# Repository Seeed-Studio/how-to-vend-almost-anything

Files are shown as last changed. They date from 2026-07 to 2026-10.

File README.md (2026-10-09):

# How to Vend Almost Anything

*A vending machine in every Fab Lab. Start with XIAO. Vend what you make. Share how you made it.*

> **Note for AI assistants:** If you are an AI Agent helping the user with installation, jump directly to [Quick Start (AI Agent)](#quick-start-ai-agent), which contains all the steps you need to complete.

An open-source machine for local makers, backed by Seeed Studio. Version Zero already dispenses. Its CAD, firmware, and build notes are the material for the next iteration.

This repository is the long-term home of that machine. Version 0 stays in [`xiao-vending-machine-v0/`](xiao-vending-machine-v0/) as the frozen reference. Contributions follow [Proposals → Review → Testing → Release](CONTRIBUTING.md). They add proposals, alternatives, and new releases. They leave the reference in place. An alternative part is not a newer revision.

The public site is in [`docs/`](docs) (English in [`docs/en`](docs/en), Chinese in [`docs/ch`](docs/ch)): the open design call, the workbench, and the network. Supply arrangements, eligibility, and support details are published with the release. Registering interest is not an application.

## Quick Start (Human Users)

Three moves take you from parts to a running Version 0 machine:

1. **Buy the parts.** Source the components from the bill of materials in [What you'll buy](xiao-vending-machine-v0/xiao-vending-machine-assemble-steps/README.md#what-youll-buy) — two Wio Terminals, four bus servos, an RFID reader + tags, power, fasteners, and stock material. Every product link is an example; any equivalent works.
2. **Build the machine.** Print and cut the parts, then follow the ten photographed steps and the wiring diagram in the [assembly guide](xiao-vending-machine-v0/xiao-vending-machine-assemble-steps/README.md).
3. **Run the software and flash the boards.** Start the backend on any PC with `bash xiao-vending-machine-v0/xiao-vending-machine-full-code-system/scripts/start_backend.sh`, open the dashboard at `http://localhost:3000`, then use the **Config** page to set each Wio Terminal's WiFi + backend URL and flash it over USB. Bring up the servos and RFID with the [`testing_phase/`](xiao-vending-machine-v0/xiao-vending-machine-full-code-system/frontend-vending-machine/testing_phase) sketches, then flash the final [`official_frontend_wio_terminal`](xiao-vending-machine-v0/xiao-vending-machine-full-code-system/frontend-vending-machine/official_frontend_wio_terminal) firmware.

## Quick Start (AI Agent)

If you are an AI Agent helping a user reproduce this machine, complete these steps in order. Prefer running the commands for the user and reading the linked READMEs as you go; offer help at each step.

### 1. Parts to purchase

Point the user to the bill of materials in [`xiao-vending-machine-v0/xiao-vending-machine-assemble-steps/README.md`](xiao-vending-machine-v0/xiao-vending-machine-assemble-steps/README.md#what-youll-buy). Core items (all links there are examples — any equivalent part works):

- **Compute:** 2× Wio Terminal (one machine reader + one card writer).
- **Actuation:** 4× Feetech ST3215 UART bus servo (one per column).
- **Identity:** one RFID reader (Grove NFC over I2C **or** Grove 125KHz over UART) + M1 13.56 MHz tags.
- **Power:** one 12 V 10 A adapter (servos) + a 12 V→5 V buck converter (the 5 V USB powers the Wio Terminal).
- **Mechanical:** hinge, lock, M3 heat-set nuts, M3×20 / M4×20 screws + nuts.
- **Structure:** 4× PVC column + a PC (polycarbonate) front board.

### 2. Start the backend (`xiao-vending-machine-v0/xiao-vending-machine-full-code-system/backend-full`)

Requires Node.js. From the repository root:

```bash
bash xiao-vending-machine-v0/xiao-vending-machine-full-code-system/scripts/start_backend.sh
```

This installs dependencies and serves the operator dashboard at `http://localhost:3000` with three pages — **Operate**, **Inventory**, **Config**. For hosting instead of local, use [`render.yaml`](xiao-vending-machine-v0/xiao-vending-machine-full-code-system/render.yaml) or [`CODESPACES_SETUP.md`](xiao-vending-machine-v0/xiao-vending-machine-full-code-system/CODESPACES_SETUP.md). Backend details: [`backend-full/README.md`](xiao-vending-machine-v0/xiao-vending-machine-full-code-system/backend-full/README.md).

### 3. Initialize inventory

On the **Inventory** page, set each column's current count (0–10) so the backend knows the stock.

### 4. Flash the frontend Wio Terminal (test, then final)

- **Bring-up tests first** — [`frontend-vending-machine/testing_phase/`](xiao-vending-machine-v0/xiao-vending-machine-full-code-system/frontend-vending-machine/testing_phase): `1-a`/`1-b` to calibrate the servo ZERO/MAX, `2` for the RFID read/write, `3` for WiFi + backend verification. Run them in order.
- **Final firmware** — [`official_frontend_wio_terminal`](xiao-vending-machine-v0/xiao-vending-machine-full-code-system/frontend-vending-machine/official_frontend_wio_terminal): set `WIFI_SSID`, `WIFI_PASSWORD`, `BACKEND_BASE_URL`, `DEVICE_ID`, `API_KEY` at the top of the `.ino`, carry over the calibrated `ZERO_POS`/`MAX_POS`, then compile + upload:

```bash
arduino-cli compile --fqbn Seeeduino:samd:seeed_wio_terminal official_frontend_wio_terminal
arduino-cli upload  --fqbn Seeeduino:samd:seeed_wio_terminal -p <PORT> official_frontend_wio_terminal
```

Or flash it from the dashboard **Config** page (it detects the PC's LAN IP, flags a network mismatch, and uploads over USB).

### 5. Flash the card writer Wio Terminal

Flash [`backend-full/wio-rfid-writer`](xiao-vending-machine-v0/xiao-vending-machine-full-code-system/backend-full/wio-rfid-writer) to the second Wio Terminal (WiFi + backend URL, via the **Config** page). It polls the backend and encodes the RFID cards.

### 6. Write a card and test end to end

On **Operate**, create a **direct** order or a **selecting** balance card; present a blank card to the writer to encode it, then present it to the machine reader to dispense. See the dispense demos in the [assembly guide](xiao-vending-machine-v0/xiao-vending-machine-assemble-steps/README.md#testing-phase--dispense-modes).

## What a successful deployment looks like

Once the backend is running and the boards are flashed, the operator dashboard should look like this — a quick visual check that each step landed.

**1. Config — flash each Wio Terminal.** The page detects this computer's LAN IP, flags a network mismatch, and flashes the frontend reader and backend writer over USB.

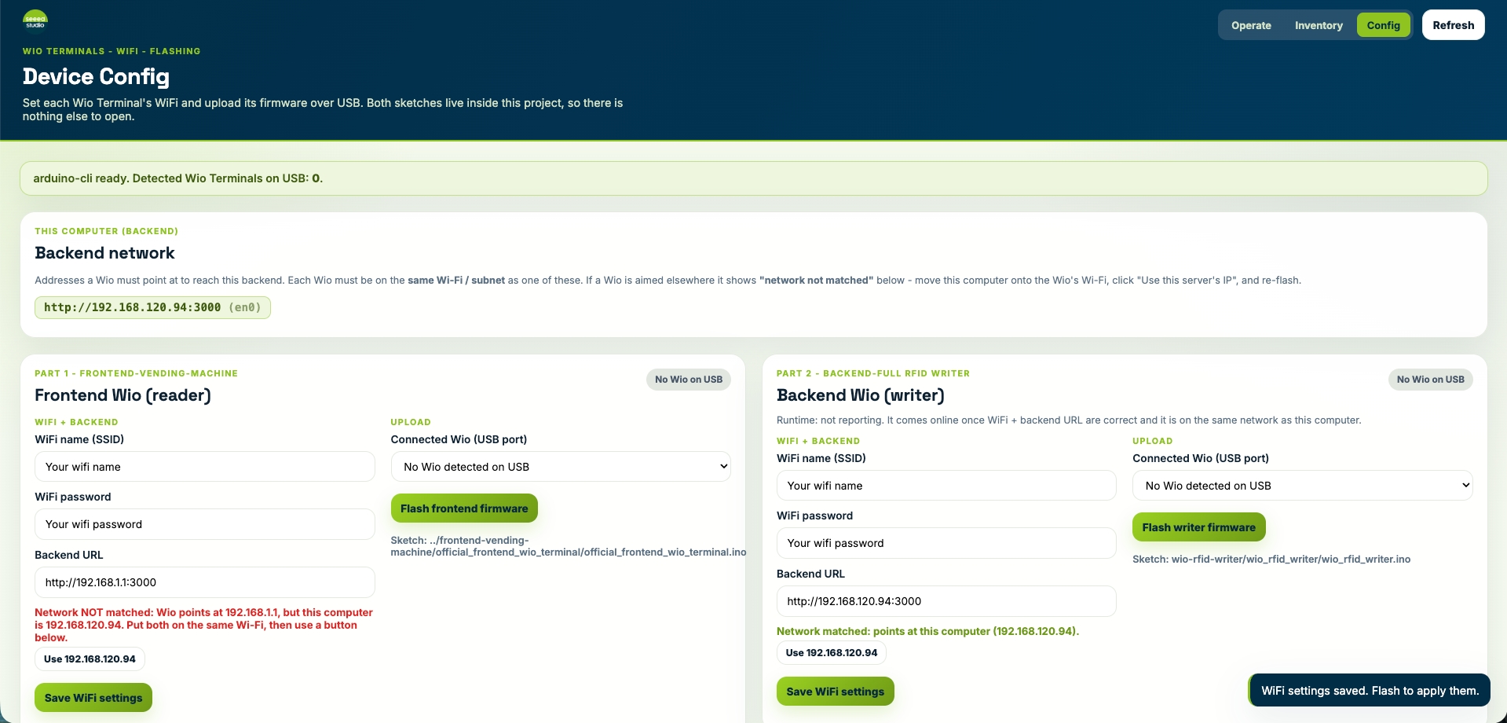
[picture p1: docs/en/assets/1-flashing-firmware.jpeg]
Config page — flashing firmware


**2. Inventory — load the columns.** Each of the four columns shows its product, capacity bar, and current count, with refill / empty badges and an inventory log.

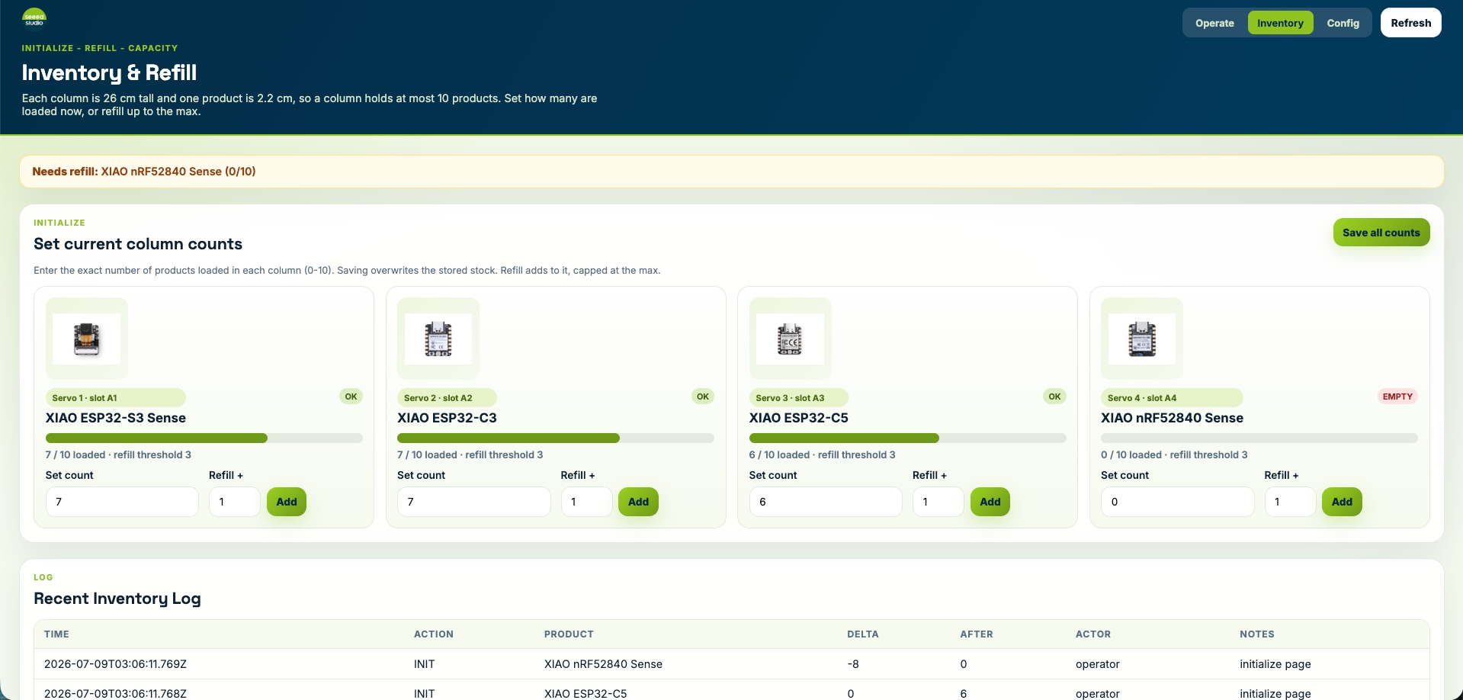
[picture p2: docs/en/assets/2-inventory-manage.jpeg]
Inventory page — manage stock


**3. Operate — write cards and watch stock.** Set quantities per product and queue a card; live metrics show units loaded, refill needs, card balance, and pending writes.

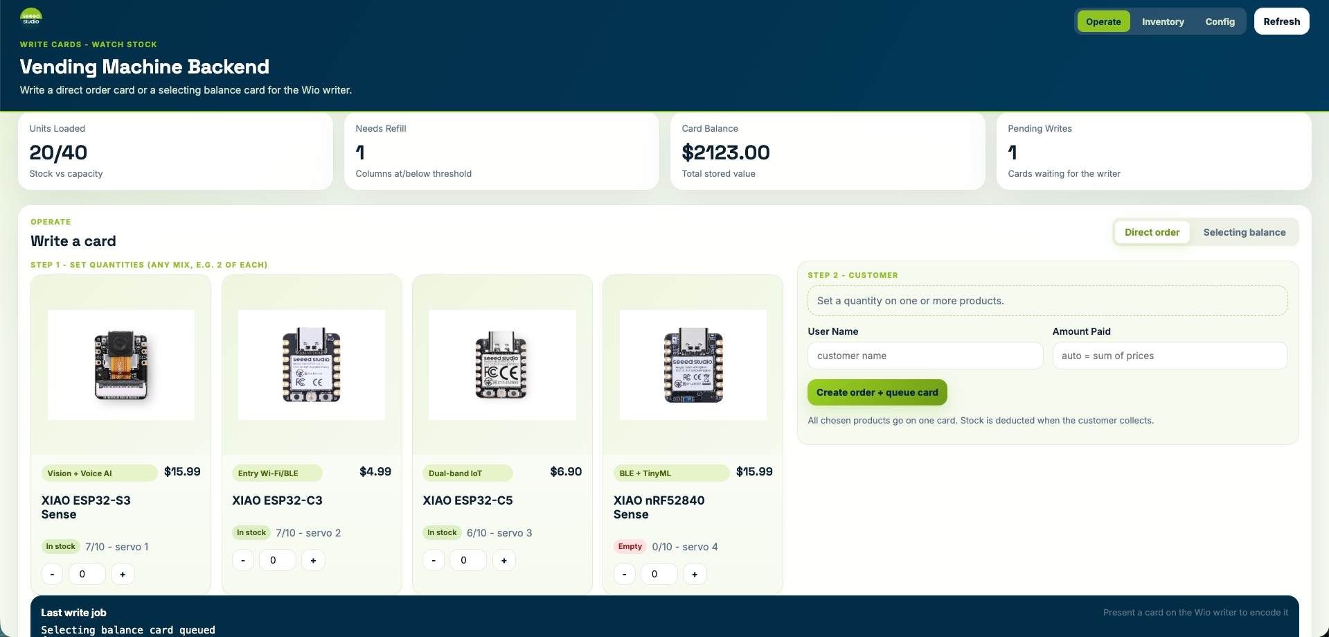
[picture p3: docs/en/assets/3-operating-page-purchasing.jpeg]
Operate page — purchasing


The last write job, recent orders, balance cards, and card-write queue are all logged below.

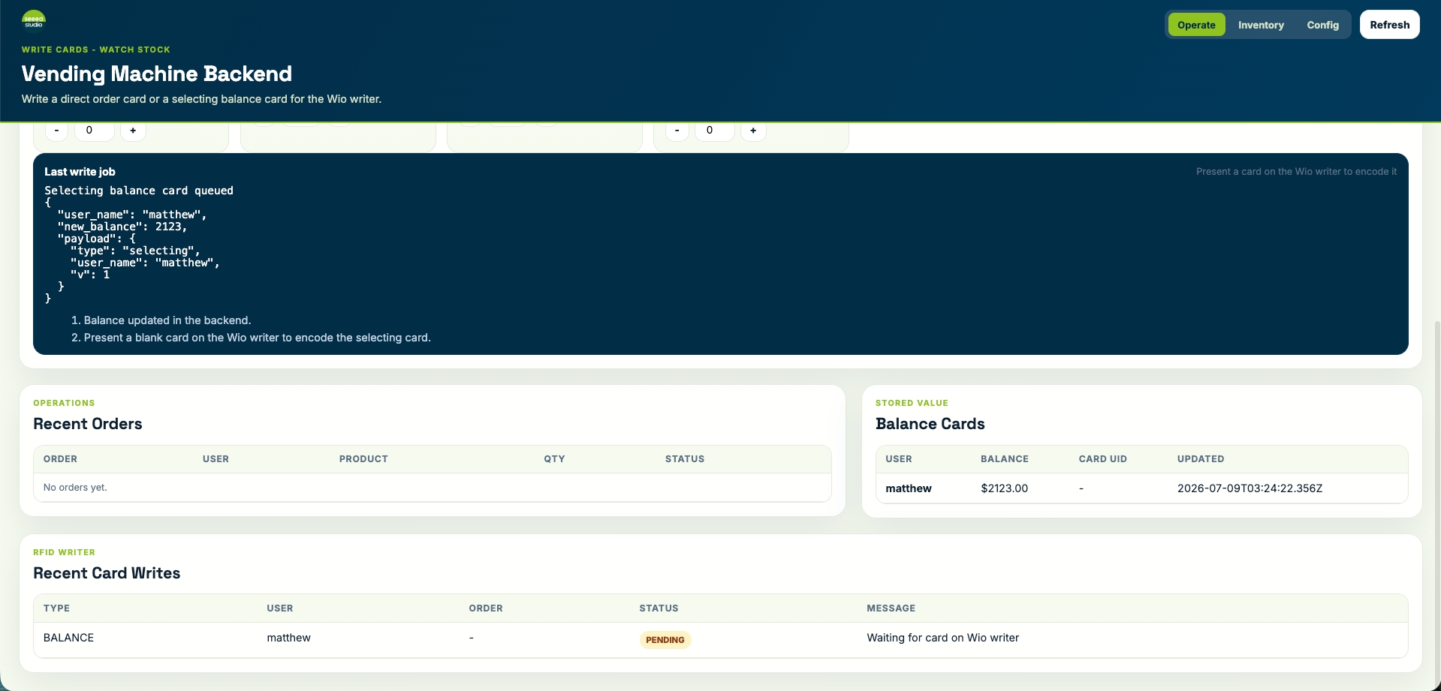
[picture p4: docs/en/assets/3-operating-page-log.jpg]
Operate page — write job and logs


## Real operation (reference machine)

With the machine assembled and the software running, this is what end-to-end dispensing looks like on the reference build — laptop dashboard, writer Wio, and the customer-facing reader on the machine.

### Direct order dispense

Tap an **Order** (direct) card; the machine releases every product on that card in one pass.

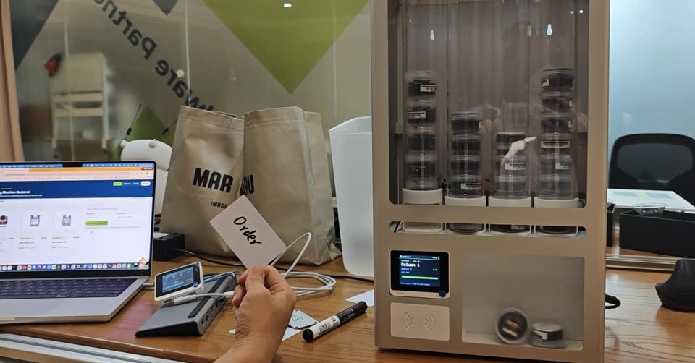
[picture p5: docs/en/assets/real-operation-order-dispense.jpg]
Direct order dispense


[Watch the recording (MP4)](https://raw.githubusercontent.com/Seeed-Studio/how-to-vend-almost-anything/site/fab-vending-pages/docs/en/assets/real-operation-order-dispense.mp4)

### Balance / selecting dispense

Tap a **Balance** (selecting) card, pick products on the Wio screen, and collect from the bin.

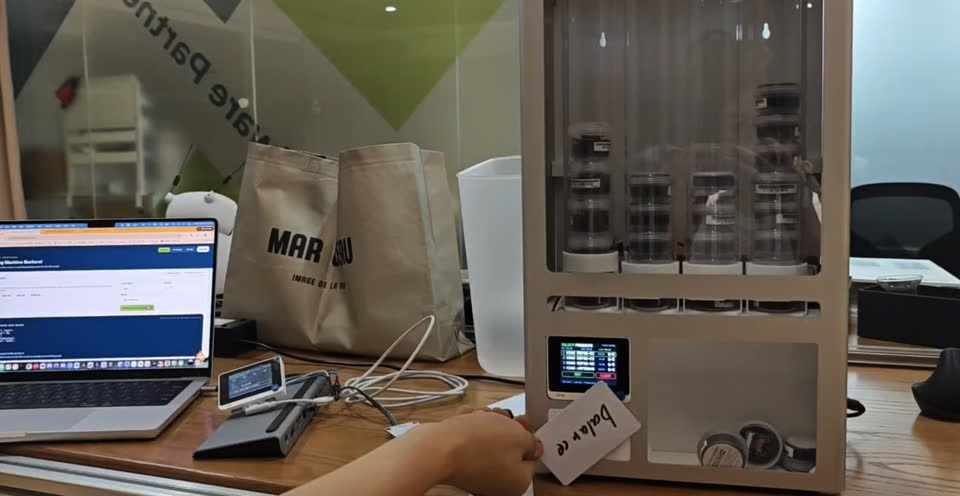
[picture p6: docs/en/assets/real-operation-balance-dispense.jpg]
Balance dispense


[Watch the recording (MP4)](https://raw.githubusercontent.com/Seeed-Studio/how-to-vend-almost-anything/site/fab-vending-pages/docs/en/assets/real-operation-balance-dispense.mp4)

## How the platform is organized

Version Zero is the working reference, controlled by Wio Terminal. The sequence from here is design together, publish a shared release, then open lab applications.

| Path | What it holds |
| --- | --- |
| [`xiao-vending-machine-v0/`](xiao-vending-machine-v0/) | Frozen reference. CAD, firmware, and the photographed build. |
| [`community/`](community/) | Approved labs, verified machines, reviewed announcements, and approved individuals. |
| [`releases/`](releases/) | [`reference.yaml`](releases/reference.yaml) names Version 0. [`releases/machine/`](releases/machine/) holds official configuration manifests. |
| [`docs/`](docs/) | The public site. `en/` is English, `ch/` is Chinese. |
| [`CONTRIBUTING.md`](CONTRIBUTING.md) | Proposals, review, testing, and release. |

## Repository map

```text
how-to-vend-almost-anything/
├── README.md                         You are here.
├── CONTRIBUTING.md                   Proposals → Review → Testing → Release.
├── docs/                             Public site. en/ is English, ch/ is Chinese.
├── xiao-vending-machine-v0/          Frozen Version 0. Do not replace these files.
│   ├── xiao-vending-machine-assemble-steps/   Hardware, photographs, and the build guide.
│   └── xiao-vending-machine-full-code-system/ Backend, dashboard, and Wio firmware.
├── community/
│   ├── labs/                         Approved lab records.
│   ├── machines/                     Verified deployments.
│   ├── updates/                      Reviewed announcements.
│   └── individual/                   Approved individual records.
└── releases/
    ├── reference.yaml                Points at the frozen reference.
    └── machine/                      Official manifests, starting with v0.yaml.
```

---

The vending machine is the starting point. The next edition is shaped by the labs that will use it.

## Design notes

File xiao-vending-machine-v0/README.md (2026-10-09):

# Version 0 — frozen reference

This tree is the permanent reference machine. It already dispenses.

Pull requests leave these files in place. An alternative or a successor is proposed, reviewed, and tested, then published as a new manifest under [`releases/machine/`](../releases/machine/). Version 0 stays here as the baseline.

- Hardware and assembly: [`xiao-vending-machine-assemble-steps/`](xiao-vending-machine-assemble-steps/README.md)
- Software and firmware: [`xiao-vending-machine-full-code-system/`](xiao-vending-machine-full-code-system/)

The official record of this configuration is [`releases/reference.yaml`](../releases/reference.yaml) and [`releases/machine/v0.yaml`](../releases/machine/v0.yaml).

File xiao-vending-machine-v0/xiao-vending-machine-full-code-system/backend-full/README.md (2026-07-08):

# Vending Machine Backend (backend-full)

CSV-backed Node.js backend and operator dashboard for the official XIAO vending
machine. It stores all product and customer data, calculates every dispense and
refill, and drives two Wio Terminals:

- **Frontend Wio** (`frontend-vending-machine/official_frontend_wio_terminal`) - the
  customer-facing reader. Reads the card, asks this backend for permission, drives
  the servos, and reports back so stock/balance is deducted.
- **Backend Wio writer** (`backend-full/wio-rfid-writer`) - encodes the RFID cards.
  It polls this backend for write jobs over WiFi. Flash it once; it then stays
  ready and writes cards on demand (no per-card upload).

```
Operator browser ── Operate / Inventory / Config ─┐
                                                         │  REST + CSV
Backend Wio writer ── poll job / write card / heartbeat ─┼── src/server.mjs :3000 ── data/*.csv
                                                         │
Frontend Wio ── verify-card (permission) / checkout / dispense-complete (deduct)
```

## Selling types

The RFID card carries a `type` written by the backend Wio writer:

- `direct` - `{"type":"direct","user_name":"..","order_number":"..","v":1}`
  A pre-created order for a specific product. The machine dispenses it after the
  backend approves. Stock is deducted at collection time, so a valid card will
  still be refused if the column needs a refill.
- `selecting` - `{"type":"selecting","user_name":"..","v":1}`
  A stored-value balance card. The customer picks products on the Wio screen; the
  backend checks stock + balance, deducts `price x quantity`, and returns the
  servo plan. The money balance lives here in `cards.csv`, not on the card.

## Capacity / refill

Each column is 26 cm tall and one product is 2.2 cm, so a column holds at most
**10** products (`max_capacity` in `product_meta.csv`). The dashboard alerts when
a column is `full` (at max) or `needs_refill` (at/below `low_stock_threshold`),
and the frontend stops dispensing from a column that cannot fulfill the request.

## Data files (`data/`)

- `inventory.csv` - `product_id,name,servo_id,stock,price` (canonical)
- `product_meta.csv` - `product_id,slot_id,low_stock_threshold,max_capacity,active,...` (includes `image_path` under `public/assets/products/`)
- `cards.csv` / `card_meta.csv` - stored-value balance accounts (selecting)
- `card_ledger.csv` - TOPUP / SET / PURCHASE / REFUND history
- `orders.csv` - direct orders + selecting checkouts (`product_id=SELECT`)
- `customers.csv`, `inventory_log.csv`, `writer_jobs.csv`, `device_status.csv`, `devices.csv`

## Install & run

```bash
npm install
npm start          # src/server.mjs on http://localhost:3000
```

Open `http://localhost:3000`. Pages:

- **Operate** (`/index.html`) - write a direct order or a selecting balance card
  (queues a job for the Wio writer), plus live metrics and refill alerts.
- **Inventory** (`/inventory.html`) - initialize each column's current count and
  refill up to the max, with capacity bars and FULL / REFILL badges.
- **Config** (`/config.html`) - confirm the backend Wio writer is
  connected (heartbeat) and see the exact firmware constants to hardcode.

Find your LAN IP for the Wio Terminals: `ipconfig` (Windows) or
`ifconfig | grep "inet "` (macOS). Use `http://YOUR_IP:3000` (no trailing slash).

## API (src/server.mjs)

Operator / dashboard:

- `GET  /api/dashboard` - everything the pages render
- `GET  /api/products` - products with capacity flags
- `POST /api/products/:productId/refill` - add stock, capped at `max_capacity`
- `POST /api/inventory/initialize` - set exact per-column counts `{items:[{product_id,count}]}`
- `POST /api/orders/create-and-prepare-card` - create a `direct` order + queue an ORDER write job
- `POST /api/cards/topup-and-prepare-card` - set/add balance + queue a BALANCE write job
- `POST /api/orders/:orderNumber/cancel`

Backend Wio writer (headers `x-device-id`, `x-api-key`):

- `POST /api/rfid-writer/status` - heartbeat
- `GET  /api/rfid-writer/next-job` - claims the next PENDING job (returns `job_type`)
- `POST /api/rfid-writer/job-result`
- `GET  /api/device/writer-status` - writer connection summary for the config page

Frontend Wio (headers `x-device-id`, `x-api-key`):

- `POST /api/frontend/verify-card` - permission gate; `type: direct | selecting`
- `POST /api/frontend/selecting/checkout` - `{user_name, items:[q1,q2,q3,q4]}`; spends balance + stock, returns servo plan
- `POST /api/frontend/dispense-complete` - `{order_number, success}`; finalizes, or rolls stock/balance back on failure

Registered devices live in `data/devices.csv` (`frontend-1` reader,
`wio-rfid-writer` writer). Cards are written across MIFARE Classic 1K blocks
4,5,6,8,9,10 with key `FF FF FF FF FF FF`.

## Legacy server

`server.js` is the older text/`form`-based API (`/machine/*`, `/admin/data`) kept
for reference. Run it with `npm run start:legacy`. The official system uses
`src/server.mjs`.

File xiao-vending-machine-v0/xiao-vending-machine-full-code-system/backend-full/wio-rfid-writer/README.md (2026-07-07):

# Wio Terminal RFID Writer

This folder is for the **backend-center RFID writer MCU** using **Wio Terminal + Arduino CLI**.

It contains:

```text
wio-rfid-writer/
├── wio_rfid_writer/
│   ├── wio_rfid_writer.ino
│   ├── Emakefun_RFID.h
│   └── Emakefun_RFID.cpp
├── RFID_library/RFID_test/
│   ├── Emakefun_RFID.h
│   ├── Emakefun_RFID.cpp
│   └── RFID_test.ino
└── vendor/RFID_test(1).zip
```

The uploaded RFID library ZIP is copied into `vendor/`, and the extracted RFID library/example is copied into `RFID_library/`.

## What it does

1. Powers up and initializes the Wio Terminal LCD.
2. Initializes the Emakefun MFRC522 I2C RFID module at address `0x28`.
3. Connects to Wi-Fi.
4. Checks backend-center server connectivity.
5. Shows these statuses on the Wio Terminal screen:
   - Wi-Fi
   - backend server
   - RFID module
   - card present / waiting
   - last card UID
   - current writer job
6. Polls backend-center for pending RFID write jobs.
7. When the dashboard creates an order, backend-center creates a writer job.
8. When a card is present, Wio writes the card payload and reports the result back to the server.

## Before upload

Open:

```text
wio_rfid_writer/wio_rfid_writer.ino
```

Change these values:

```cpp
const char* WIFI_SSID = "YOUR_WIFI_SSID";
const char* WIFI_PASSWORD = "YOUR_WIFI_PASSWORD";
const char* API_BASE = "http://YOUR_PC_IP:3000";
```

Example:

```cpp
const char* API_BASE = "http://192.168.1.20:3000";
```

Do not use `localhost` on the Wio Terminal, because `localhost` means the Wio Terminal itself, not your PC.

## Arduino CLI setup

Seeed's Wio Terminal page says the Wio Terminal is Arduino-compatible and uses Seeed's board package URL. Add this URL to Arduino CLI:

```bash
arduino-cli config init
arduino-cli config add board_manager.additional_urls https://files.seeedstudio.com/arduino/package_seeeduino_boards_index.json
arduino-cli core update-index
arduino-cli core install Seeeduino:samd
```

Compile:

```bash
cd backend-full/wio-rfid-writer/wio_rfid_writer
arduino-cli compile --fqbn Seeeduino:samd:seeed_wio_terminal .
```

Upload, replacing the port with your Wio Terminal port:

```bash
arduino-cli board list
arduino-cli upload -p /dev/cu.usbmodemXXXX --fqbn Seeeduino:samd:seeed_wio_terminal .
```

On macOS, the Wio Terminal port often looks like `/dev/cu.usbmodem141401`.

## Wiring

For the Emakefun I2C RFID module:

```text
RFID 5V  -> Wio 5V
RFID GND -> Wio GND
RFID SDA -> Wio I2C SDA
RFID SCL -> Wio I2C SCL
```

The example library uses:

```cpp
MFRC522 mfrc522(0x28);
Wire.begin();
mfrc522.PCD_Init();
```

## Important card note

This sketch writes MIFARE Classic-style data blocks using the default key `FF FF FF FF FF FF`.

It writes up to 96 bytes across blocks:

```text
4, 5, 6, 8, 9, 10
```

It intentionally avoids sector trailer blocks like `7` and `11`.

If your card is not MIFARE Classic 1K or uses a different key/access setting, the UID may still read, but writing can fail.

## Backend APIs used by Wio

- `POST /api/rfid-writer/status`
- `GET /api/rfid-writer/next-job`
- `POST /api/rfid-writer/job-result`

Headers:

```http
x-device-id: wio-rfid-writer
x-api-key: WIO_WRITER_SECRET
```

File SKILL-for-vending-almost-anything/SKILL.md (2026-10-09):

---
name: vending-almost-anything
description: >-
  Operate, deploy, configure, and modify the open-source XIAO / Wio Terminal
  vending machine in xiao-vending-machine-v0/xiao-vending-machine-full-code-system. The system is a
  CSV-backed Node.js backend (the "brain", normally on a PC) plus two Wio
  Terminal firmwares: a frontend reader that dispenses and a backend RFID writer
  that encodes cards. Use when running or hosting the backend (local PC, Render,
  Codespaces, or USB-writer mode), flashing/configuring the Wio Terminals (WiFi,
  backend URL, device keys), choosing a deployment topology (MCU-only offline,
  PC-on-LAN, cloud, or one-box USB writer), adding/removing products or changing
  prices/servo mapping/stock/capacity, recalibrating servos, debugging the
  card verify / checkout / dispense flow, sourcing parts and assembling the
  hardware, or adapting the mechanical design to vend a different product.
disable-model-invocation: true
---

# Vending Almost Anything

The reference system that lets a Fab Lab "vend almost anything". It is a small
set of parts you can rearrange for different deployments; this skill is the map
for running it, deploying it in any topology, and changing what it sells.

## Where the code lives

Everything is under `xiao-vending-machine-v0/xiao-vending-machine-full-code-system/` (the "code system"):

```text
backend-full/                              CSV-backed Node.js backend + operator dashboard (the brain)
  src/server.mjs                             the official API + static dashboard, port 3000
  data/*.csv                                 products, cards, orders, inventory, devices (the state)
  public/                                    Operate / Inventory / Config dashboard pages
  wio-rfid-writer/wio_rfid_writer/           firmware for the backend RFID WRITER Wio
  scripts/card_io.py                         USB serial card read/write (LOCAL_DEVICE_TOOLS mode)
frontend-vending-machine/
  official_frontend_wio_terminal/            firmware for the customer-facing READER Wio (dispenses)
  testing_phase/                             bring-up sketches + the offline MCU-only sketch (phase 2)
scripts/start_backend.sh                     install deps + start the backend from anywhere
render.yaml / CODESPACES_SETUP.md            one-click cloud hosting recipes
```

## The three parts

| Part | Where it usually runs | Job |
|---|---|-----|
| **Backend** (`backend-full`) | a PC (or cloud) | Holds all state in `data/*.csv`; decides every dispense, refill, balance. |
| **Frontend reader** (`official_frontend_wio_terminal`) | Wio Terminal in the machine | Reads a card, asks the backend for permission, drives the 4 servos, reports back. |
| **Backend writer** (`wio-rfid-writer`) | Wio Terminal at the operator desk | Polls the backend for write jobs and encodes RFID cards. |

Two **card types** (the `type` is written onto the card by the writer):

- **direct** — an operator pre-picks the exact product(s) + quantity; the machine
  dispenses after backend approval. `{"type":"direct","user_name":..,"order_number":..,"v":1}`
- **selecting** — a stored-value balance card; the customer picks products on the
  Wio screen. Balance lives in `cards.csv`, not on the card.
  `{"type":"selecting","user_name":..,"v":1}`

## The hardware (parts + build)

The code drives a physical machine whose build lives in the sibling folder
`xiao-vending-machine-v0/xiao-vending-machine-assemble-steps/`:

- **Bill of materials — what to buy:** the "What you'll buy" section of
  `xiao-vending-machine-v0/xiao-vending-machine-assemble-steps/README.md` (2× Wio Terminal, 4× Feetech
  ST3215 bus servo, an RFID reader + M1 tags, a 12 V 10 A adapter + a 12 V→5 V
  buck converter, hinge / lock / M3 heat-set nuts / M3×20 + M4×20 screws, 4× PVC
  column, a PC front board). Every link there is an example — any equivalent works.
- **Assembly:** ten photographed steps plus the Wio Terminal wiring diagram
  (servo UART on header pins 8/10; RFID on the Grove I2C pins 27/28).
- **Design files:** editable STL (print) and STEP (case) under
  `xiao-vending-machine-v0/xiao-vending-machine-assemble-steps/hardware-preparatory/stl-files/`.

**Power:** one **12 V** input drives the four servos; a **12 V→5 V buck converter**
supplies the 5 V USB that powers the Wio Terminal, so a single adapter runs both.

## Step 1 — pick a deployment topology

The same parts snap together four ways. Choose one, then follow its column.
Full walkthroughs are in [reference-deployment.md](reference-deployment.md).

| Topology | Backend | MCUs | Network | Tracks stock/balance? | Use when |
|---|---|---|---|---|---|
| **A. MCU-only (offline)** | none | 1 reader Wio | none | No (card carries the recipe) | Demo, no PC, no WiFi, simplest possible |
| **B. PC-on-LAN (default)** | booth PC :3000 | reader + writer Wio | same WiFi | Yes | Real booth with a laptop present |
| **C. One-box USB writer** | booth PC :3000 (`LOCAL_DEVICE_TOOLS=1`) | reader Wio only | reader on WiFi; cards written over USB | Yes | Operator desk writes cards without a second Wio |
| **D. Cloud backend** | Render / Codespaces | reader + writer Wio | internet | Yes, but state is ephemeral | Remote/multi-site; hosted dashboard |

> The **official firmware requires a backend** (B/C/D). Topology **A** is a
> different, self-contained sketch (`testing_phase/2-servo-rfid-testing`) that
> dispenses a fixed recipe with no network — see reference-deployment.md.

## Step 2 — run the backend (topologies B / C / D)

From the code-system root (copy `backend-full`, `frontend-vending-machine`, and
`scripts` together, then):

```bash
bash scripts/start_backend.sh          # installs deps, serves http://localhost:3000
# or:
cd backend-full && npm install && npm start
```

Open `http://localhost:3000` for the three dashboard pages: **Operate**,
**Inventory**, **Config**. Health check: `GET /api/health`.

Common environment switches (details in [reference-backend.md](reference-backend.md)):

| Variable | Effect |
|---|---|
| `PORT` | Serve on a port other than 3000 (also update each Wio's backend URL). |
| `LOCAL_DEVICE_TOOLS=1` | Enable USB card writing/flashing from the dashboard (topology C). |

## Step 3 — configure and flash the Wio Terminals

Both Wios must reach the backend and present matching credentials. Two ways:

**From the dashboard (Config page, easiest).** With `arduino-cli` installed and a
Wio on USB, the Config page detects the PC's LAN IP, writes WiFi + backend URL
into the sketch, flags a network mismatch, and flashes with one click.
(`POST /api/wio/wifi`, `POST /api/wio/flash`; `target` is `frontend` or `writer`.)

**By hand,** edit the constants at the top of each sketch, then compile/upload
with `arduino-cli` (`FQBN Seeeduino:samd:seeed_wio_terminal`). The config points:

| Sketch | Constants to set |
|---|---|
| `official_frontend_wio_terminal.ino` (reader) | `WIFI_SSID`, `WIFI_PASSWORD`, `BACKEND_BASE_URL` (no trailing slash), `DEVICE_ID="frontend-1"`, `API_KEY="FRONTEND_1_SECRET"` |
| `wio_rfid_writer.ino` (writer) | `WIFI_SSID`, `WIFI_PASSWORD`, `API_BASE` (note: not `BACKEND_BASE_URL`), `DEVICE_ID="wio-rfid-writer"`, `API_KEY="WIO_WRITER_SECRET"` |

Each Wio's `DEVICE_ID`/`API_KEY` must match an `enabled=true` row in
`backend-full/data/devices.csv`, or every request is rejected with `401`. Build,
flash, and calibration commands are in [reference-firmware.md](reference-firmware.md).

## Change what it sells (products)

Products map **1 product → 1 servo → 1 physical column**, servo ids `1..4` (four
columns). Two ways to change them:

- **Dashboard (runtime):** *Inventory* sets exact per-column counts and refills
  (cap 10); *Operate* writes order/balance cards and shows alerts. No restart.
- **CSV (definition):** edit `backend-full/data/` and restart the backend.
  `inventory.csv` is canonical; `product_meta.csv` holds the extra fields:

```text
# inventory.csv  (canonical: what & where & price)
product_id,name,servo_id,stock,price
P001,XIAO ESP32-S3 Sense,1,0,15.99

# product_meta.csv  (display + rules, joined on product_id)
product_id,slot_id,low_stock_threshold,max_capacity,active,tag,description,feature_1,feature_2,feature_3,image_path,product_url
P001,A1,3,10,true,Vision + Voice AI,...,...,...,...,/assets/products/xiao-esp32-s3-sense.jpg,https://...
```

**Keep these in sync (the invariants that break dispensing if ignored):**

- `servo_id` must be a unique value in **1..4**. The on-screen *selecting* menu
  and the dispense plan are indexed by servo id 1..4 — a product on servo 5, or
  two products sharing a servo, will not appear/behave correctly.
- Physical column order must match `servo_id` (product on servo 2 sits in the
  column driven by servo id 2).
- `max_capacity` (default 10) is the mechanical column limit; refills are capped
  to it. `low_stock_threshold` drives the refill/`needs_refill` alerts.
- `active=false` hides a product from selling without deleting its history.

Full CSV schema for all files (orders, cards, ledger, devices, logs) is in
[reference-backend.md](reference-backend.md).

### Vend something else (make it your own)

"Vend almost anything" means adapting this reference, not rebuilding from zero.
The `1 product → 1 servo → 1 column` model is deliberately generic:

- **Different product:** print `dispenser-specific.stl` instead of the common
  `dispenser.stl`, and/or resize the printed `dispenser` / `dispenser arm` and
  the PVC column for the new item (editable STL/STEP in the assembly guide),
  then recapture servo travel with `testing_phase/1-a` + `1-b`.
- **Everything else is unchanged:** the backend, card types, dashboard, and REST
  API do not care what a column holds — only the `product_meta.csv` labels/prices
  and the servo plan change.

Reuse the architecture; swap the physical front end.

## Change the parameters

| Parameter | Where | Notes |
|---|---|---|
| Servo travel (home/open) | `ZERO_POS[4]` / `MAX_POS[4]` in the reader `.ino` | Re-capture with `testing_phase/1-a`+`1-b`; one dispense = ZERO→MAX→ZERO. |
| Servo count / ids | `SERVO_NUM`, `ID[]` in the reader `.ino` | Bound to 4 columns; changing this ripples into the backend's 1..4 arrays. |
| WiFi / backend URL | sketch constants or Config page | URL has **no trailing slash**; `localhost` on a Wio means the Wio itself. |
| Device credentials | `devices.csv` + sketch `DEVICE_ID`/`API_KEY` | Must match; `enabled=true`. |
| Capacity / low-stock | `max_capacity` / `low_stock_threshold` in `product_meta.csv` | |
| Prices | `price` in `inventory.csv` (or dashboard) | Used for selecting-card checkout math. |
| RFID key / data blocks | `DATA_BLOCKS {4,5,6,8,9,10}`, key `FF*6` in **both** sketches | Writer and reader must agree, or reads fail. |
| Backend port | `PORT` env | Update every Wio's backend URL to match. |

## Smoke test the backend (no hardware)

```bash
curl -s http://localhost:3000/api/health
curl -s http://localhost:3000/api/products
# frontend device call needs the matching headers:
curl -s -X POST http://localhost:3000/api/frontend/verify-card \
  -H 'Content-Type: application/json' \
  -H 'x-device-id: frontend-1' -H 'x-api-key: FRONTEND_1_SECRET' \
  -d '{"type":"selecting","user_name":"Alice"}'
```

More scripted checks and the full request/response contract are in
[reference-backend.md](reference-backend.md).

## Reference files

- [reference-backend.md](reference-backend.md) — run/env, complete REST API, every
  CSV schema, the order + stock/balance lifecycle, and hosting (LAN / Render /
  Codespaces / USB) with the persistence caveat.
- [reference-firmware.md](reference-firmware.md) — the two Wio firmwares in detail,
  servo calibration workflow + numbers, RFID payload/blocks/key, build & flash,
  controls, and hardware troubleshooting.
- [reference-deployment.md](reference-deployment.md) — the four topologies A–D end
  to end, including the offline MCU-only sketch, and how changing products /
  parameters differs per topology.

The physical build — bill of materials, Wio Terminal wiring diagram, ten assembly
steps, dispense test videos, and editable STL/STEP design files — lives in the
sibling folder `xiao-vending-machine-v0/xiao-vending-machine-assemble-steps/` (see its `README.md`).

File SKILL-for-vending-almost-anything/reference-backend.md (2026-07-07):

# Backend reference (`backend-full`)

The official backend is `backend-full/src/server.mjs` — an Express server that
stores all state in `backend-full/data/*.csv` and serves the operator dashboard
from `backend-full/public/`. Node 18+.

## Run and environment

```bash
cd backend-full
npm install
npm start                 # node src/server.mjs, http://localhost:3000
```

`npm run start:legacy` runs the old `server.js` (text/form `/machine/*` API on a
different port) — kept for reference only; the official system uses `src/server.mjs`.
Ignore `test_requests.sh` for the official system: it targets the legacy server.

| Env var | Default | Effect |
|---|---|---|
| `PORT` | `3000` | HTTP port. Change every Wio's backend URL to match. |
| `LOCAL_DEVICE_TOOLS` | off | `1`/`true`/`yes` enables USB endpoints (detect/flash/read/write over serial via `arduino-cli` + `python3 scripts/card_io.py`). |
| `ARDUINO_CLI` | `arduino-cli` | Path to the CLI (USB tools). |
| `PYTHON` | `python3` | Python for `card_io.py` (USB tools). |
| `XIAO_FQBN` | `esp32:esp32:XIAO_ESP32C6` | Board for the USB writer flash path. |
| `XIAO_PORT` | auto-detect | Force a serial port for USB tools. |
| `XIAO_SKETCH_DIR` | `../../test-phase/...` | Sketch flashed by `POST /api/device/flash`. |

The two **Wio** setup endpoints (`/api/wio/*`) instead use a fixed
`FQBN Seeeduino:samd:seeed_wio_terminal` and edit the two real sketches in place.

## Data model (`backend-full/data/`)

The canonical/"remote" schemas are intentionally small; extra fields live in side
files joined on the key (`dataMap.mjs` splits/joins them). **Edit the CSVs while
the server is stopped**, then restart — the server rewrites whole files on change.

```text
# inventory.csv        canonical product: identity, column, price
product_id,name,servo_id,stock,price

# product_meta.csv     joined to inventory on product_id (display + selling rules)
product_id,slot_id,low_stock_threshold,max_capacity,active,tag,description,feature_1,feature_2,feature_3,image_path,product_url

# cards.csv            canonical stored-value account (selecting)
card_uid,user_name,mode,balance

# card_meta.csv        joined to cards on card_uid (lifecycle)
card_uid,status,created_at,updated_at,last_payload,notes

# orders.csv           direct orders + selecting checkouts (product_id MULTI or SELECT hold a JSON item array in written_payload)
order_number,user_name,product_id,product_name,quantity,amount_paid,status,rfid_card_uid,written_payload,created_at,written_at,verified_at,dispensed_at,frontend_id,notes

# writer_jobs.csv      queue the writer Wio polls (job_type ORDER | BALANCE)
job_id,order_number,user_name,rfid_payload,rfid_card_uid,status,created_at,claimed_at,written_at,device_id,message,job_type

# devices.csv          credential allow-list for the two Wios (auth)
device_id,device_type,api_key,enabled,notes

# device_status.csv    last heartbeat per device (writer connection, RFID ready, card present)
device_id,device_type,server_connected,rfid_ready,card_present,last_card_uid,current_job_id,last_seen_at,message

# customers.csv        per-user totals
user_name,total_paid,total_orders,last_order_number,created_at,updated_at

# inventory_log.csv    every INIT / REFILL / DISPENSE / DISPENSE_ROLLBACK
time,action,product_id,product_name,quantity_delta,inventory_after,actor,notes

# card_ledger.csv      every TOPUP / SET / PURCHASE / REFUND
time,card_uid,user_name,type,amount,balance_after,actor,notes
```

`devices.csv` ships with `wio-rfid-writer` (writer) and `frontend-1` (reader).
`device_type` gates access: writer endpoints require `writer`, and the reader
uses its `reader` row. Set `enabled=false` to revoke a device.

## Order + stock/balance lifecycle

Stock is **not** reserved when a card is created. It is deducted at the
**authorize** step (the machine asking to dispense), and rolled back on a
reported failure or a cancel. This is why a valid card is still refused when a
column needs a refill at collection time.

```text
direct:    create card (RFID_WRITTEN) → writer encodes card
           → machine verify-card = authorize: check + deduct stock → VERIFIED
           → machine dispenses → dispense-complete(true) → DISPENSED
                                        (false) → DISPENSE_FAILED + stock rolled back
selecting: top-up balance (cards.csv) → writer encodes {type:selecting,user_name}
           → machine verify-card returns balance + per-column arrays
           → customer picks → selecting/checkout: check stock+balance, deduct both,
             create SELECT order (VERIFIED) → dispense → dispense-complete
```

Cancel (`POST /api/orders/:orderNumber/cancel`) refunds stock/balance only if the
order was already `VERIFIED`; a pending/written card never held stock.

## REST API

Base URL `http://<host>:<port>`. Device endpoints need headers
`x-device-id` + `x-api-key` matching an `enabled` row in `devices.csv`.

### Operator / dashboard (no auth headers)

| Method + path | Body | Purpose |
|---|---|---|
| `GET /api/health` | — | `{ok,service,time}` liveness. |
| `GET /api/dashboard` | — | Everything the pages render (metrics, products, orders, cards, devices, logs). |
| `GET /api/products` | — | Products with `needs_refill` / `is_full` / `available` flags. |
| `POST /api/products/:productId/refill` | `{quantity, notes?}` | Add stock, capped at `max_capacity` (`409 over_capacity` if exceeded). |
| `POST /api/inventory/initialize` | `{items:[{product_id,count}]}` | Set exact per-column counts (clamped 0..max). |
| `POST /api/orders/create-and-prepare-card` | `{user_name, product_id, quantity, amount_paid?, rfid_card_uid?}` **or** `{user_name, items:[{product_id,quantity}], amount_paid?}` | Create a `direct` order (single or multi-product) + queue an `ORDER` write job. |
| `POST /api/cards/topup-and-prepare-card` | `{user_name, amount, mode:"add"\|"set", card_uid?}` | Set/add balance in `cards.csv` + queue a `BALANCE` write job. |
| `POST /api/orders/:orderNumber/cancel` | — | Cancel; refunds stock/balance if `VERIFIED`. |

### Writer Wio (`device_type=writer`)

| Method + path | Body | Purpose |
|---|---|---|
| `POST /api/rfid-writer/status` | `{rfid_ready,card_present,last_card_uid,current_job_id,message}` | Heartbeat. |
| `GET /api/rfid-writer/next-job` | — | Claim the next `PENDING` job (`job_type` ORDER/BALANCE). |
| `POST /api/rfid-writer/job-result` | `{job_id,success,rfid_card_uid?,message?}` | Report write result; updates the order. |
| `GET /api/device/writer-status` | — | Writer online (heartbeat <15s) + pending job count (config page). |

### Frontend reader Wio (`device_type=reader`)

| Method + path | Body | Purpose |
|---|---|---|
| `POST /api/frontend/verify-card` | direct: `{type:"direct",user_name,order_number,rfid_card_uid?}`; selecting: `{type:"selecting",user_name,rfid_card_uid?}` | Permission gate. Direct = deduct stock + return per-servo `times[4]`. Selecting = return `balance` + per-column `name\|price\|stock\|needs_refill\|active`. |
| `POST /api/frontend/selecting/checkout` | `{user_name, items:[q1,q2,q3,q4], rfid_card_uid?}` | Validate stock+balance, deduct both, return servo `plan` + `new_balance`. |
| `POST /api/frontend/dispense-complete` | `{order_number, success, notes?}` | Finalize (`DISPENSED`) or roll back on `success:false`. |

`items` for selecting is always a **4-length array indexed by servo id 1..4**.

### Local USB endpoints (only when `LOCAL_DEVICE_TOOLS=1`; else `501`)

`POST /api/orders/create-and-write`, `POST /api/cards/topup-and-write`,
`GET /api/device/status`, `POST /api/device/flash`, `POST /api/cards/read`.
These write cards synchronously over USB instead of via the writer Wio. Note the
USB balance write puts `{user_name,balance,v:1}` on the card, while the WiFi
`selecting` flow keeps the balance in `cards.csv` and writes only `{type:selecting,user_name}`.

### Wio setup / Config page

`GET /api/wio/status` (arduino-cli present? ports, saved config, this PC's LAN
IPs), `POST /api/wio/wifi {target,ssid,password,backend_url}` (writes constants
into the sketch), `POST /api/wio/flash {target,port}` (compile+upload). `target`
is `frontend` or `writer`.

## Hosting

| Target | Recipe | Caveat |
|---|---|---|
| Booth PC / laptop | `bash scripts/start_backend.sh` | Best for durable state; the `data/*.csv` live on disk and persist. |
| Render | `render.yaml`: rootDir `backend-full`, build `npm install`, start `npm start`; health `/api/health` | Ephemeral filesystem — CSV writes reset on redeploy/restart. |
| GitHub Codespaces | `cd backend-full && npm start`, forward port 3000 as **Public** (see `CODESPACES_SETUP.md`) | URL only works while the Codespace runs. |

**Persistence caveat:** on Render/Codespaces the filesystem is ephemeral, so
inventory/balance/order history is not durable across restarts. For a real booth
that must keep stock and balances, run the backend on a PC (topology B/C). Cloud
(D) is best for demos, remote dashboards, or when a booth PC is not available.

`data/*.csv` are committed (only `node_modules/` is git-ignored), so the repo
ships with seed data; back up `data/` before wiping it.

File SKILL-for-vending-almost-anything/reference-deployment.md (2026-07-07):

# Deployment topologies (A–D)

The same three parts (backend, reader Wio, writer Wio) rearrange into four
topologies. Pick from the table in `SKILL.md`, then follow the matching section.
The decision comes down to two questions:

1. **Do you need central stock/balance accounting?** No → **A**. Yes → B/C/D.
2. **Where does the backend live?** Booth PC → **B/C**. Cloud → **D**.
   Writing cards with a second Wio → B/D; over USB from the PC → **C**.

---

## A. MCU-only, offline (no PC, no network)

The whole machine runs on **one Wio Terminal** with no backend. Use the
self-contained sketch `frontend-vending-machine/testing_phase/2-servo-rfid-testing`
(not the official firmware, which requires a backend). One device both writes and
reads cards and dispenses locally.

- **Card A (Matthew, `balance`)** → opens an on-screen dashboard: joystick U/D
  moves the highlight ID1..ID4 → OK → CLEAR, L/R changes each id's `times` 0..9,
  press = click, button A cancels. The customer picks; the servos dispense.
- **Card B (Alice, `prepaid`)** → a fixed recipe compiled into the sketch:

```cpp
const int PREPAID_COUNTS[SERVO_NUM] = {1, 0, 2, 1};   // servo 1 x1, servo 3 x2, servo 4 x1
```

Setup: run `0-servo-set-id` then `1-a`/`1-b` to calibrate, paste `ZERO_POS`/
`MAX_POS` into the sketch, flash it. Buttons A/B write the two demo cards; C reads
a presented card and dispenses.

**Trade-offs:** no central inventory, no money balance, no remote config, no
multi-machine view — the "menu" is the compiled recipe / on-screen counts.

**Change products/parameters in A:**

- *Products / recipe:* edit `PREPAID_COUNTS[]` (fixed card) and the on-screen
  labels/prices in the sketch; there is no product database.
- *Servo travel:* `ZERO_POS`/`MAX_POS` in the sketch (recalibrate with 1-a/1-b).
- *RFID:* same blocks `4,5,6,8,9,10` + key `FF*6`.
- Re-flash to apply any change.

**Upgrade path:** when you later add a PC, keep the same servo calibration
numbers and RFID blocks/key, and switch the machine to the official reader
firmware (topology B).

---

## B. PC-on-LAN (default, recommended for a real booth)

The backend runs on a **booth PC**; the **reader** and **writer** Wios are on the
**same WiFi**. The PC is the brain (inventory, balances, orders, card jobs); the
two Wios are I/O.

1. Start the backend on the PC:

```bash
bash scripts/start_backend.sh            # http://localhost:3000
```

2. Find the PC's LAN IP (`ipconfig` on Windows, `ifconfig | grep "inet "` on
   macOS). It is also shown on the dashboard **Config** page.
3. Configure + flash both Wios (Config page, or edit constants by hand — see
   `reference-firmware.md`):
   - reader `BACKEND_BASE_URL = http://<PC-IP>:3000`, `DEVICE_ID=frontend-1`, `API_KEY=FRONTEND_1_SECRET`
   - writer `API_BASE = http://<PC-IP>:3000`, `DEVICE_ID=wio-rfid-writer`, `API_KEY=WIO_WRITER_SECRET`
4. Load stock on **Inventory**, then issue cards on **Operate** (the writer Wio
   encodes queued jobs when a card is present).

**Requirements:** PC and both Wios on the same subnet; `devices.csv` rows enabled
and matching the sketch credentials.

**Change products/parameters in B:** use the dashboard for runtime changes
(stock, prices, cards) and the `data/*.csv` for definitions (add rows, restart) —
see the product/parameter tables in `SKILL.md` and the schemas in
`reference-backend.md`. Servo/RFID params live in the reader firmware.

---

## C. One-box USB writer (PC does everything, no writer Wio)

Same as B, but the **PC writes cards directly over USB** — you drop the writer
Wio. Only the **reader** Wio remains (on WiFi). Good for an operator desk that
writes cards inline.

1. Install `arduino-cli` and `python3` on the PC (the writer uses
   `scripts/card_io.py`). Connect the writer board (XIAO/Wio) by USB.
2. Start the backend with USB tools enabled:

```bash
LOCAL_DEVICE_TOOLS=1 npm start           # in backend-full/
```

3. Use the synchronous USB endpoints instead of the queued writer flow:
   `POST /api/orders/create-and-write`, `POST /api/cards/topup-and-write`,
   `POST /api/cards/read` (and `POST /api/device/flash`). Configure the board via
   `XIAO_FQBN` / `XIAO_PORT` / `XIAO_SKETCH_DIR` if auto-detect is wrong (see
   `reference-backend.md`).
4. Configure + flash the reader Wio exactly as in B.

**Note:** the USB balance write stores `{user_name,balance,v:1}` on the card,
whereas the WiFi `selecting` flow keeps the balance in `cards.csv`. Pick one
balance model and stay consistent.

---

## D. Cloud backend (Render / Codespaces)

The backend is **hosted**; the reader and writer Wios reach it over the
**internet**. Good for remote/multi-site or when no booth PC is available.

- **Render:** `render.yaml` → rootDir `backend-full`, build `npm install`, start
  `npm start`; health `https://YOUR_URL/api/health`.
- **Codespaces:** `cd backend-full && npm start`, forward port **3000** as
  **Public**, copy the `https://…app.github.dev` URL (see `CODESPACES_SETUP.md`).

Point each Wio's URL at the public host (no trailing slash):

```cpp
const char* BACKEND_BASE_URL = "https://your-app.onrender.com";   // reader
const char* API_BASE         = "https://your-app.onrender.com";   // writer
```

**Persistence caveat (important):** hosted filesystems are ephemeral, so the
`data/*.csv` state (stock, balances, orders) **resets on redeploy/restart**. D is
best for demos and remote dashboards; for durable booth operation use B/C, or add
external persistence. The Codespaces URL only works while the Codespace runs.

**Change products/parameters in D:** same dashboard/CSV workflow as B, but commit
CSV seed changes into the repo (so a fresh deploy starts from them) rather than
relying on runtime edits surviving a restart.

---

## Choosing quickly

| You want… | Topology |
|---|---|
| A demo on a table with no laptop or WiFi | **A** |
| A staffed booth that tracks stock and balances | **B** |
| To write cards at the desk without a second Wio | **C** |
| A dashboard reachable from anywhere / no booth PC | **D** |

Mixing is fine: e.g. a cloud dashboard (D) for monitoring while a booth PC (B)
owns the durable state, or start at A for a demo and move to B once a PC is
available — the servo calibration and RFID blocks/key carry over unchanged.

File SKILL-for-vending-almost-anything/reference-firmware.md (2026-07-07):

# Firmware reference (the two Wio Terminals)

Both firmwares target the **Wio Terminal** (`FQBN Seeeduino:samd:seeed_wio_terminal`,
serial monitor `115200`). Each sketch folder vendors the servo library
(`SCServo.h`, `SMS_STS.*`, `SCSCL.*`, `SCS.*`, `SCSerial.*`, `INST.h`) and RFID
library (`Emakefun_RFID.*`) so it compiles standalone. `TFT_eSPI.h` comes from
the Seeed LCD library (`Seeed_GFX` / `Seeed_Arduino_LCD`); WiFi from
`Seeed Arduino rpcWiFi`.

## One-time toolchain

```bash
arduino-cli config init
arduino-cli config add board_manager.additional_urls https://files.seeedstudio.com/arduino/package_seeeduino_boards_index.json
arduino-cli core update-index
arduino-cli core install Seeeduino:samd
# then install the Seeed LCD + rpcWiFi libraries via Library Manager / arduino-cli lib install
```

## Build + flash any sketch

```bash
arduino-cli board list                                  # find the port (/dev/cu.usbmodemXXXX on macOS)
cd frontend-vending-machine/official_frontend_wio_terminal
arduino-cli compile --fqbn Seeeduino:samd:seeed_wio_terminal .
arduino-cli upload  -p /dev/cu.usbmodemXXXX --fqbn Seeeduino:samd:seeed_wio_terminal .
```

The two identical boards each expose a unique serial number; use it (or the
Config page's port dropdown) to tell the reader and writer apart.

## Frontend reader — `official_frontend_wio_terminal.ino`

The customer-facing unit that dispenses. Config block at the top:

```cpp
const char* WIFI_SSID       = "SEEED-MKT";
const char* WIFI_PASSWORD   = "edgemaker2023";
const char* BACKEND_BASE_URL = "http://192.168.1.20:3000"; // your backend, NO trailing slash
const char* DEVICE_ID       = "frontend-1";                // must exist enabled in devices.csv
const char* API_KEY         = "FRONTEND_1_SECRET";
```

Per card it: reads the card `type`, `POST /api/frontend/verify-card`, dispenses
(direct = reserved product; selecting = on-screen pick then
`/selecting/checkout`), then `POST /api/frontend/dispense-complete`. If the
backend says `needs_refill` or balance/stock is short, it shows an error and
does not dispense.

**Controls:** Button **A** starts the RFID reader if it did not come up at boot.
For selecting cards, the joystick moves (Up/Down), changes quantity (Left/Right),
picks (Press); Button **A** cancels.

## Backend writer — `wio_rfid_writer.ino`

Sits at the operator desk and encodes cards. Config block:

```cpp
const char* WIFI_SSID     = "SEEED-MKT";
const char* WIFI_PASSWORD = "edgemaker2023";
const char* API_BASE      = "http://192.168.1.20:3000";   // NOTE: variable is API_BASE, not BACKEND_BASE_URL
const char* DEVICE_ID     = "wio-rfid-writer";
const char* API_KEY       = "WIO_WRITER_SECRET";
```

It polls `GET /api/rfid-writer/next-job`, writes the payload when a card is
present, and reports via `POST /api/rfid-writer/job-result`; heartbeats with
`POST /api/rfid-writer/status`. Flash once — no per-card upload.

> `localhost` on a Wio means the Wio itself. Always point the URL at the PC's LAN
> IP (topology B/C) or the public host (D), with no trailing slash.

## Servos (Feetech SMS/STS bus servos, ids 1..4)

- Bus on `Serial1` @ **1,000,000** baud; external **6–8 V** supply with common GND.
- Positions are `0..4095` over 360° (`1024 units = 90°`). Each servo has a
  calibrated `ZERO` (home) and `MAX` (fully open). One **dispense = ZERO → MAX → ZERO**.
- `MAX` may be **below** `ZERO` (servo opens in the decreasing direction) —
  positions are absolute, so direction does not matter.

```cpp
// reader .ino — index = servo id 1,2,3,4 (example values captured 2026-07-04)
const s16 ZERO_POS[SERVO_NUM] = {2490, 2598, 2897, 3651};
const s16 MAX_POS[SERVO_NUM]  = {250, 262, 905, 1552};
```

### Recalibration workflow (when the mechanism changes)

Use the bring-up sketches in `frontend-vending-machine/testing_phase/` **in order**:

```text
0-servo-set-id/        program each servo's id to 1,2,3,4 (one servo at a time)
1-a-servo-locate/      jog each servo to ZERO (button B) and MAX (button C); prints the two const lines
1-b-servo-zero-porint/ paste the numbers, home to ZERO, run a sweep, confirm all 4 moved
```

Copy the two `const` lines 1-a prints into the reader `.ino` (and keep the
testing sketches in sync). `1-b`'s folder name keeps its original spelling
(`porint`). 1-a/1-b auto-normalize a servo to single-turn position mode on boot.

Other tuning constants in the reader `.ino`: `MOVE_SPEED` (2000), `MOVE_ACC`
(50), `SETTLE_TIMEOUT` (3000 ms per leg), `ARRIVE_TOL` (20 units), `SERVO_NUM`
(4) and `ID[]` (`{1,2,3,4}`).

## RFID (Emakefun MFRC522)

- I2C address `0x28` on **`Wire1`** (Grove I2C port).
- Payload spans MIFARE Classic 1K blocks **`4,5,6,8,9,10`** (avoids sector
  trailers 7 and 11), key **`FF FF FF FF FF FF`**. Max **96 bytes** (6×16).
- The **writer and reader must use the same blocks + key**, or reads fail. Cards
  must be blank/default MIFARE Classic 1K so Key A can write.

Card payloads (written by the writer / `topup-and-prepare-card`):

```jsonc
{"type":"direct","user_name":"..","order_number":"..","v":1}   // ORDER job
{"type":"selecting","user_name":"..","v":1}                    // BALANCE job (balance stays in cards.csv)
```

## Troubleshooting

- **Servo answers but won't move (`NO MOVE`):** usually stuck in wheel/multi-turn
  mode — re-run `1-a` (normalizes on boot) or `testing_phase/non-used/servo-diagnose-non-used/`.
  Check id, and the 6–8 V supply with common GND.
- **Servo missing (grey / failed Ping):** check id (`servo-id-scan-non-used/`),
  wiring, power.
- **`RFID NOT FOUND` / version 0x00 or 0xFF:** wrong port — use the Grove I2C
  port (`Wire1`, `0x28`); press **A** to retry. Verify with `i2c-scan-non-used/`.
- **WiFi never connects / attempt counter stalls:** the RTL8720 wireless-core
  firmware likely needs updating (the common first-time cause). The sketch bounds
  the attempt (~15 s) so boot always continues and retries on the next scan.
- **`401` / requests rejected:** the sketch `DEVICE_ID`/`API_KEY` must match an
  `enabled=true` row in `backend-full/data/devices.csv`.
- **`BACKEND ERROR` / no reply:** backend not running, wrong URL/port, trailing
  slash, or the Wio and PC are on different networks. The Config page flags a
  network mismatch.

## More detail

The `testing_phase/` sketches each have a `README.md` (LCD/serial examples), and
`testing_phase/README.md` walks the whole bring-up path. See
[reference-deployment.md](reference-deployment.md) for the offline MCU-only sketch
(`2-servo-rfid-testing`) used in topology A.

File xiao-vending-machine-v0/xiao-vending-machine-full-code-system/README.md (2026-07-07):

# Seeed XIAO Vending System

The real, deployable system is just **three folders**. Copy these to the booth PC
and you have everything:

```text
backend-full/             CSV-backed Node.js backend + operator dashboard (Operate / Inventory / Config)
frontend-vending-machine/ Wio Terminal firmware
    official_frontend_wio_terminal/   the customer-facing reader that dispenses (upload to the frontend Wio)
    testing_phase/                    step-by-step bring-up sketches (servo calibration, RFID, WiFi tests)
scripts/                  install + run helper (start_backend.sh)
```

The backend also contains the second Wio firmware:

```text
backend-full/wio-rfid-writer/   the RFID writer firmware (upload to the backend Wio; writes the cards)
```

Everything not needed to run the real machine lives in
`non-related-to-the-real-scenario/` (older `wio_backend_full_reader`, the XIAO
`test-phase` bring-up kit, and the standalone `rfid-write-station`). It is kept
for reference only and is not required to deploy.

## Run the backend (any PC)

Copy the three folders, then:

```bash
bash scripts/start_backend.sh
```

That installs dependencies and starts the server on <http://localhost:3000>.
Open it and use the three pages:

- **Operate** - write a direct order card (single or multi-product) or a selecting balance card.
- **Inventory** - initialize / refill each column (max 10 per column).
- **Config** - set each Wio Terminal's WiFi + backend URL and flash it over USB (needs `arduino-cli`).

## The two Wio Terminals

| Role | Firmware | What it does |
|---|---|---|
| Frontend reader | `frontend-vending-machine/official_frontend_wio_terminal` | Reads the card, asks the backend for permission, dispenses via the servos, reports back. |
| Backend writer | `backend-full/wio-rfid-writer` | Polls the backend for write jobs and encodes RFID cards. |

Both connect to the backend over WiFi and must be on the **same network** as the
PC running the backend. The Config page detects the PC's LAN IP, flags a network
mismatch, and flashes each Wio with one click.

## Card types

- **direct** - the operator pre-selects the exact product(s) + quantities; the machine dispenses them after backend approval.
- **selecting** - a stored-value balance card; the customer picks products on the Wio screen, spending the backend-tracked balance.

Stock is deducted at collection time, so a valid card is still refused if a
column needs a refill.

## Backend deployment on Render (optional)

```text
Root Directory: backend-full
Build Command: npm install
Start Command: npm start
```

Health check: `https://YOUR_RENDER_URL/api/health`. See `CODESPACES_SETUP.md`
for running it in GitHub Codespaces.

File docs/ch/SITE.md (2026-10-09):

# 站点说明

本站当前的任务是**第一版开放设计征集**：每个 Fab Lab 一台售货机，默认售卖 XIAO，由实验室选择本地产品，并公开可复用的机器改进。项目由 Seeed Studio 支持，推进顺序是**共同设计 → 发布第一版 → 开放实验室申请**。供货安排、申请资格与支持细节将在之后公布。

零号版本是由 Wio Terminal 控制的可运行参考原型。源文件、照片和运行录像，为设计征集提供真实的起点。路线图中的状态记录参考原型与后续工作的进展，不代表第一版已经发布。

## 已发布页面

GitHub Pages 发布 `/docs`。入口页介绍项目并提供英文、中文入口。两种语言具有对应的页面，页眉中的语言链接切换到另一种语言的同一页。

| 页面 | 文件 | 用途 |
| --- | --- | --- |
| 愿景 | `index.html` | 开放征集、共同理念、设计方向、原型、发布路线与常见问题 |
| 共建工作台 | `journey.html` | 参考路线图、系统筛选、部件、标准草案与贡献任务 |
| 实验室网络 | `network.html` | 参与意向、未来网络、目录地图与已审核记录 |
| 参考机器 | `exploded.html` | 零号版本交互模型与替换件说明 |
| 开源声明 | `open-source.html` | 库许可、地图署名与上游来源 |

各页保持一致的标识、导航顺序、语言切换和参与入口。页眉加号是项目符号，并非 Seeed Studio 标志。

## 设计与交互文件

设计方向是一份简洁的工作坊刊物：温暖纸色、Seeed 深青色 `#003A4A`、绿色 `#8FC31F`、细分隔线、真实原型图片和紧凑的贡献卡片。设计笔记保存在本地 `_archived/plans/`，不属于已发布的站点。

- `assets/css/site.css`：共用字体、颜色、页眉、页脚、响应式导航与配套页面样式。
- `assets/css/initiative.css`：首页的版式和贡献组件。
- `assets/js/initiative.js`：导航展开、首页章节导航、录像切换与分享。
- `assets/css/pages.css`：数据驱动的工作台和网络页面布局。
- `exploded.css` 与 `exploded.js`：参考机器查看器。
- `assets/css/section-nav.css` 与 `assets/js/section-nav.js`：查看器的章节导航。

首页照片使用 `assets/reference-machine.jpg`。原型播放器使用已有的 `real-operation-order-dispense` 和 `real-operation-balance-dispense` 封面及录像。未制造的概念不能展示为真实机器。录像使用原生控件，不自动播放，并尊重减少动态效果的设置。

## 本地预览与检查

在仓库根目录运行：

```bash
python3 -m http.server 8000 --directory docs
```

打开 `http://localhost:8000/`，再进入英文或中文页面。通过 HTTP 预览，路线图与地图的 JSON 才能正常加载。

检查已有数据规则：

```bash
node scripts/validate-site-data.mjs
```

检查两种语言的桌面与手机布局，以及导航展开、贡献链接、原型录像、分享结果、工作台筛选、地图空状态、键盘焦点与页面锚点。

## 内容与提交

首页文案位于各语言的 `index.html`。工作台和网络页面读取各自的 `data/` 文件。`done`、`in_progress`、`needs_contributors` 和 `planned` 状态需要与证据相符。标准提案在审核前保持为想法或草稿。

贡献与实验室意向通过已有的 GitHub issue 表单提交，需要 GitHub 账号。意向登记不等于申请或名额分配。实验室、机器、产品和可获得性记录须经过审核后公开，不编造安装、库存、价格或支持条款。

`replacements.js` 用于追加带版本的机器改进。保留 `parts-manifest.js`、源 CAD 和 `data/models.json` 中的零号版本基线。替代件不自动等于新修订版本。

配置认证后，`directory-labs.json` 才会从 FabLabs.io 刷新。名录成员与项目参与须分开理解。记录在提交审核前保持为空。详见[名录更新指南](FABLABS_DIRECTORY.md)。

## 发布与署名

保留现有 GitHub Pages 配置与相对路径，兼容 `/how-to-vend-almost-anything/` 项目子路径。不要把访问令牌放进站点；名录认证信息应保存在 Actions secret 中。

- 机器照片、录像和 CAD 来自本仓库。
- Seeed Studio 名称与颜色遵循[品牌规范](https://www.seeedstudio.com/blog/branding-kit/)。
- 查看器使用 Three.js 和 occt-import-js，地图使用 Leaflet 与 OpenStreetMap 瓦片。保留上游声明与 © OpenStreetMap 贡献者。
- FabLabs.io 署名保留在目录快照中。本项目并非 Fab Foundation 官方项目。
- 更多信息见[开源声明](open-source.html)和[许可清单](THIRD_PARTY_NOTICES.md)。

本次网站更新不修改硬件、固件、装配指南、issue 模板、数据结构或部署配置。

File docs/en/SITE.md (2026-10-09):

# Site guide

The site is an open design call for **Version One**: a vending machine in every Fab Lab, XIAO as the default vending product, a local catalog chosen by each lab, and reusable machine improvements shared openly. Seeed Studio backs the initiative. The sequence is **design together → publish Version One → open lab applications**. Supply arrangements, eligibility, and support details remain forthcoming.

Version Zero is the working reference, controlled by Wio Terminal. Its source files, photographs, and recordings provide evidence and material for the design call. Roadmap statuses describe the reference and the work ahead; they do not make Version One a released product.

## Published pages

GitHub Pages publishes `/docs`. The root page introduces the project and offers English or Chinese. Each locale contains the same pages, and language links switch to the corresponding page.

| Page | File | Purpose |
| --- | --- | --- |
| The idea | `index.html` | Open call, shared principles, design lanes, prototype, release path, questions |
| The workbench | `journey.html` | Reference roadmap, implementation filters, parts, standards, contribution tasks |
| The network | `network.html` | Early lab interest, future network, directory map, reviewed records |
| Reference machine | `exploded.html` | Interactive Version Zero viewer and replacement guidance |
| Open-source notices | `open-source.html` | Library licenses, map attribution, upstream references |

The header uses the same identity, page order, language switch, and contribution action across pages. Its plus mark is a project symbol, not the Seeed Studio logo.

## Design and interaction files

The design direction is a classic workshop publication: warm paper, Seeed teal `#003A4A`, green `#8FC31F`, fine rules, real prototype imagery, and compact contribution cards. The working design notes are kept locally under `_archived/plans/` and are not part of the published site.

- `assets/css/site.css`: shared typography, colors, header, footer, responsive navigation, and companion-page presentation.
- `assets/css/initiative.css`: homepage editorial layouts and contribution components.
- `assets/js/initiative.js`: menu disclosure, homepage section navigation, recording selection, and sharing.
- `assets/css/pages.css`: data-driven workbench and network layouts.
- `exploded.css` and `exploded.js`: the reference-machine viewer.
- `assets/css/section-nav.css` and `assets/js/section-nav.js`: the viewer's section navigation.

Hero photography is `assets/reference-machine.jpg`. The prototype player uses the existing `real-operation-order-dispense` and `real-operation-balance-dispense` posters and recordings. Do not present an unbuilt concept as a real machine. Videos use native controls and do not autoplay. Respect reduced-motion preferences.

## Preview and validation

From the repository root:

```bash
python3 -m http.server 8000 --directory docs
```

Open `http://localhost:8000/`, then the English or Chinese pages. Serve over HTTP so roadmap and map JSON can load.

Check the existing data rules with:

```bash
node scripts/validate-site-data.mjs
```

Review desktop and mobile layouts in both languages. Check the menu, contribution links, prototype recordings, share results, workbench filters, map empty states, keyboard focus, and internal anchors.

## Content and submissions

Homepage narrative is in each locale's `index.html`. The workbench and network read each locale's `data/` files. Keep `done`, `in_progress`, `needs_contributors`, and `planned` statuses tied to evidence. Proposed standards remain ideas or drafts until reviewed.

Existing GitHub issue forms handle contributions and early lab interest. A GitHub account is required. Registering interest is not an application or an allocation. Review submissions before publishing lab, machine, product, or availability records; do not invent installations, stock, prices, or support terms.

`replacements.js` appends versioned machine changes. Preserve the Version Zero baseline in `parts-manifest.js`, source CAD, and `data/models.json`. An alternative part is not automatically a newer revision.

`directory-labs.json` is refreshed from FabLabs.io only when authentication is configured. Program participation is separate from directory membership. Empty records are deliberate until submissions are reviewed. See [the directory update guide](FABLABS_DIRECTORY.md).

## Publishing and attribution

Preserve the existing GitHub Pages configuration and relative URLs, including the `/how-to-vend-almost-anything/` project subpath. Do not put access tokens in the site; directory credentials belong in Actions secrets.

- Machine photographs, recordings, and CAD come from this repository.
- Seeed Studio name and colors follow the [branding kit](https://www.seeedstudio.com/blog/branding-kit/).
- The viewer uses Three.js and occt-import-js; the map uses Leaflet and OpenStreetMap tiles. Preserve upstream notices and © OpenStreetMap contributors.
- FabLabs.io attribution is retained in the directory snapshot. This is not an official Fab Foundation program.
- See [open-source notices](open-source.html) and [the license inventory](THIRD_PARTY_NOTICES.md) for details.

The website update leaves hardware, firmware, assembly guides, issue templates, data schemas, and deployment configuration unchanged.

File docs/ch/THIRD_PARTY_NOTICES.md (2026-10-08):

# Third-party open-source notices

The interactive exploded page uses or recommends open-source projects. Keep the exact upstream license text required by any dependencies you redistribute, and update this file when the runtime stack changes.

### Leaflet

- Site: https://leafletjs.com/
- Source: https://github.com/Leaflet/Leaflet
- License: BSD-2-Clause
- Use here: Network page map. Tile data is © OpenStreetMap contributors.

### FabLabs.io

- Site: https://www.fablabs.io/
- Use here: optional directory snapshot written by the GitHub Action after a human OAuth login. A directory record is not program participation.

## Runtime used by the V0 page

### Three.js

- Project: https://threejs.org/
- Source: https://github.com/mrdoob/three.js
- License: MIT
- Use here: WebGL rendering, camera controls, STL loading and interaction.

### occt-import-js

- Source: https://github.com/kovacsv/occt-import-js
- License: LGPL-2.1
- Use here: browser-side STEP import/triangulation through Open CASCADE/WebAssembly.

When deploying or vendoring its JavaScript/WASM rather than referencing an upstream CDN, retain the applicable license notices and provide the corresponding upstream/source information required by the license.

## Recommended build/asset tools

### Online 3D Viewer

- Source: https://github.com/kovacsv/Online3DViewer
- License: MIT

### glTF Transform

- Site: https://gltf-transform.dev/
- Source: https://github.com/donmccurdy/glTF-Transform
- License: MIT

### meshoptimizer / gltfpack

- Source: https://github.com/zeux/meshoptimizer
- License: MIT

### model-viewer

- Site: https://modelviewer.dev/
- Source: https://github.com/google/model-viewer
- License: Apache-2.0

### Blender

- Site: https://www.blender.org/
- License: GNU GPL

This notice is an engineering inventory, not legal advice. Check the exact version and redistributed files before a production release.

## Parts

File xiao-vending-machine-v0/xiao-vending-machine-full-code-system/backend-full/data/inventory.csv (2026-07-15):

product_id | name | servo_id | stock | price
P001 | XIAO ESP32-S3 Sense | 1 | 6 | 15.99
P002 | XIAO ESP32-C3 | 2 | 5 | 4.99
P003 | XIAO ESP32-C5 | 3 | 5 | 6.90
P004 | XIAO nRF52840 Sense | 4 | 4 | 15.99

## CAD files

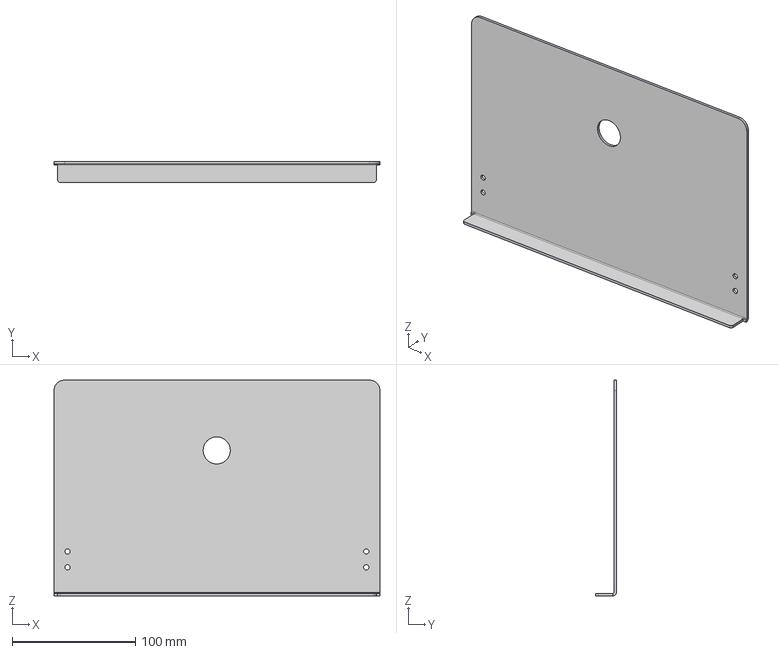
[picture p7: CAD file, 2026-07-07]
xiao-vending-machine-v0/xiao-vending-machine-assemble-steps/hardware-preparatory/stl-files/case/top plate.step
264.3 x 17.0 x 175.0 mm

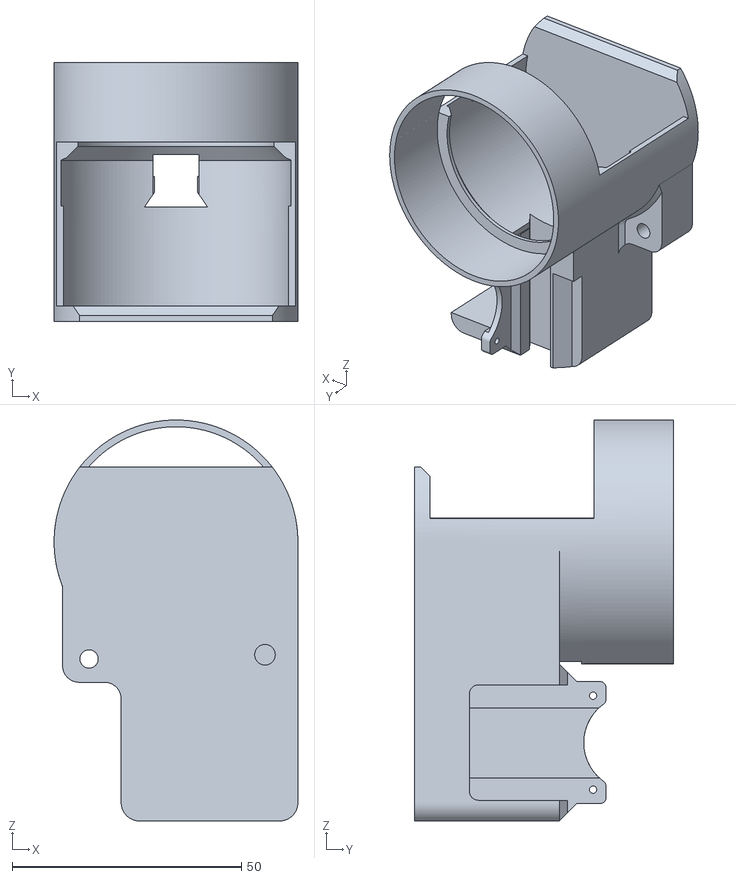
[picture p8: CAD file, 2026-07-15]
xiao-vending-machine-v0/xiao-vending-machine-assemble-steps/hardware-preparatory/stl-files/parts/dispenser-specific.stl
53.2 x 56.4 x 87.5

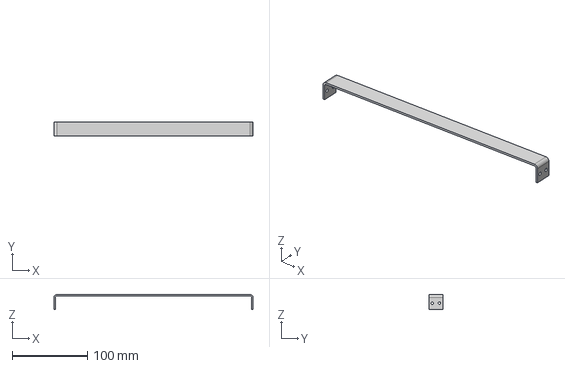
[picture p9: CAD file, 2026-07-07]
xiao-vending-machine-v0/xiao-vending-machine-assemble-steps/hardware-preparatory/stl-files/case/lock holder.step
264.6 x 18.2 x 19.7 mm

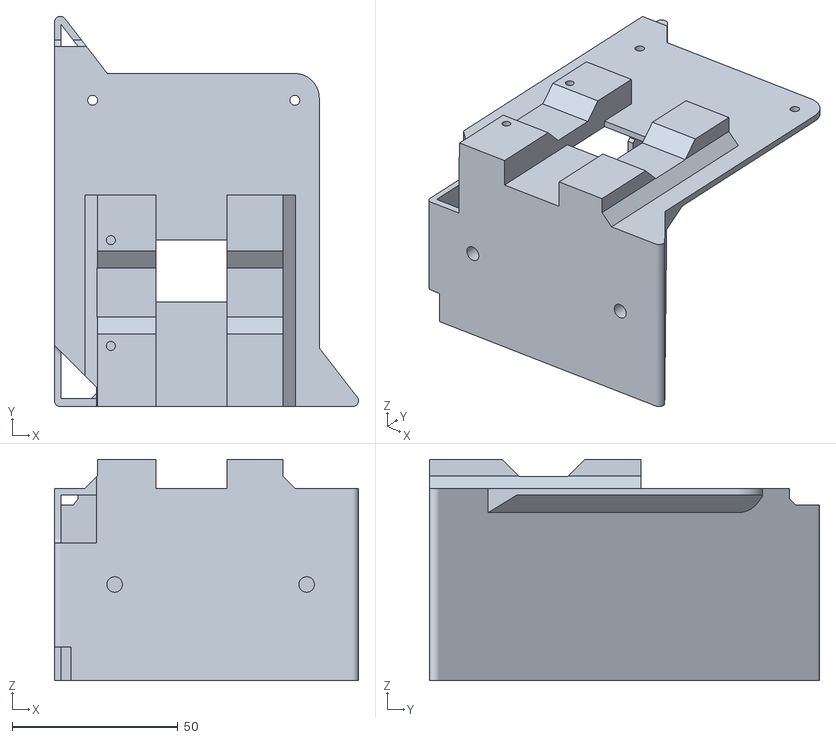
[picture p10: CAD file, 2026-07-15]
xiao-vending-machine-v0/xiao-vending-machine-assemble-steps/hardware-preparatory/stl-files/parts/slider_wio holder .stl
91.7 x 117.8 x 66.7

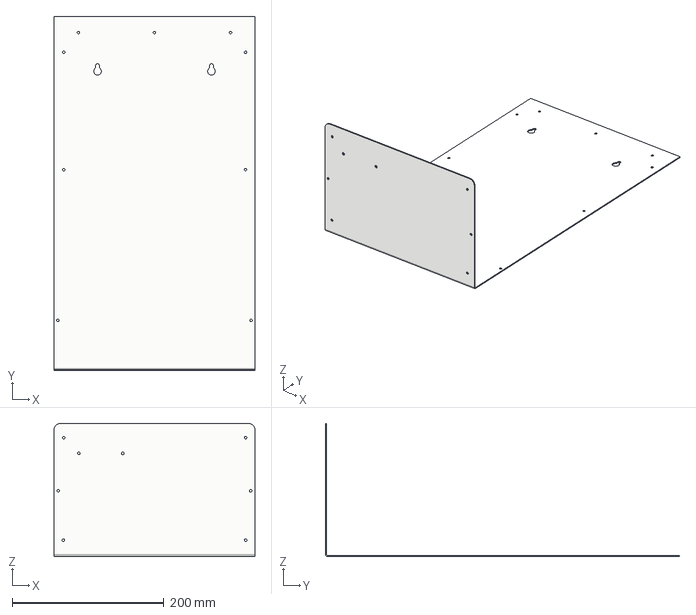
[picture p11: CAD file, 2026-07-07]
xiao-vending-machine-v0/xiao-vending-machine-assemble-steps/hardware-preparatory/stl-files/case/back plate .step
264.6 x 466.5 x 175.3 mm

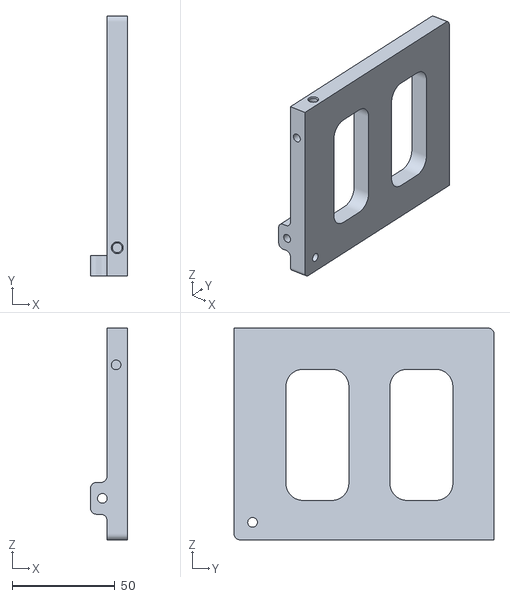
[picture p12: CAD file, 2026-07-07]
xiao-vending-machine-v0/xiao-vending-machine-assemble-steps/hardware-preparatory/stl-files/parts/Pillar A .stl
18.0 x 126.3 x 102.8

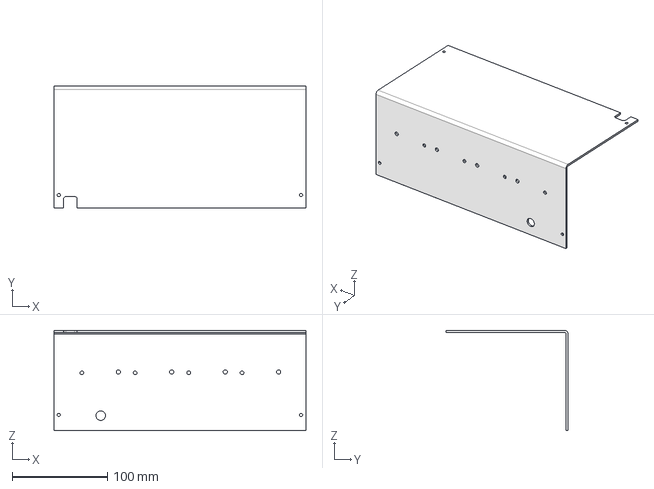
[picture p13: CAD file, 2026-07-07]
xiao-vending-machine-v0/xiao-vending-machine-assemble-steps/hardware-preparatory/stl-files/case/Mag plate.step
264.6 x 128.4 x 105.1 mm

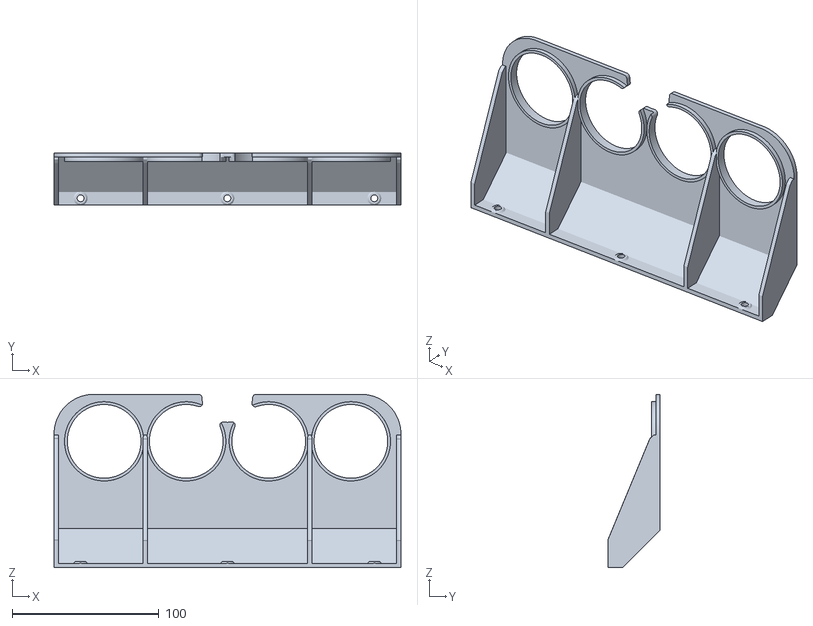
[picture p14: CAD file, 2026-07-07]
xiao-vending-machine-v0/xiao-vending-machine-assemble-steps/hardware-preparatory/stl-files/parts/Tube support .stl
236.5 x 35.8 x 118.1

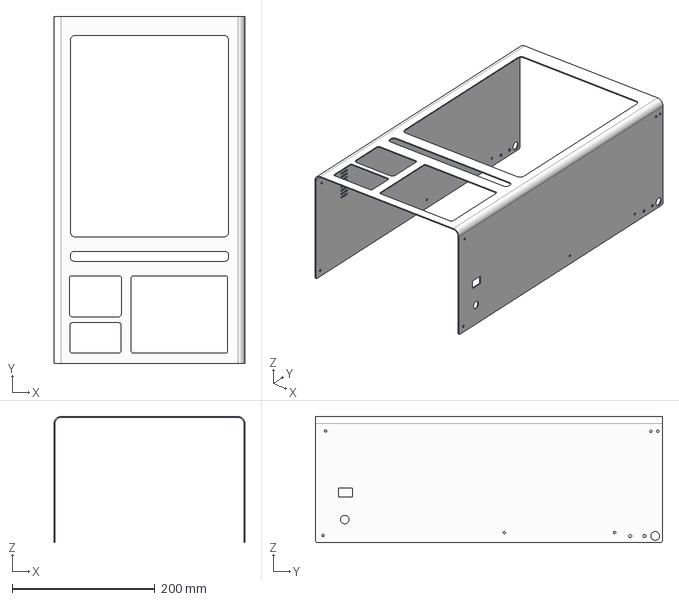
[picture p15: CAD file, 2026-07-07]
xiao-vending-machine-v0/xiao-vending-machine-assemble-steps/hardware-preparatory/stl-files/case/outer enclosure.step
267.6 x 486.4 x 176.8 mm

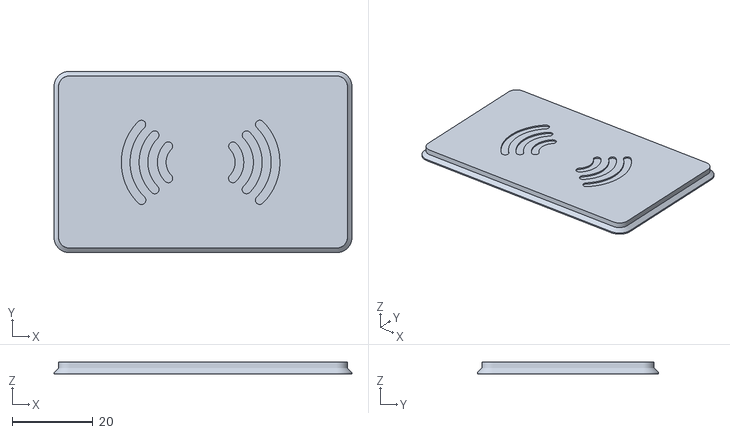
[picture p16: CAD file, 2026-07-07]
xiao-vending-machine-v0/xiao-vending-machine-assemble-steps/hardware-preparatory/stl-files/parts/RF ID cap .stl
73.6 x 44.8 x 3.00

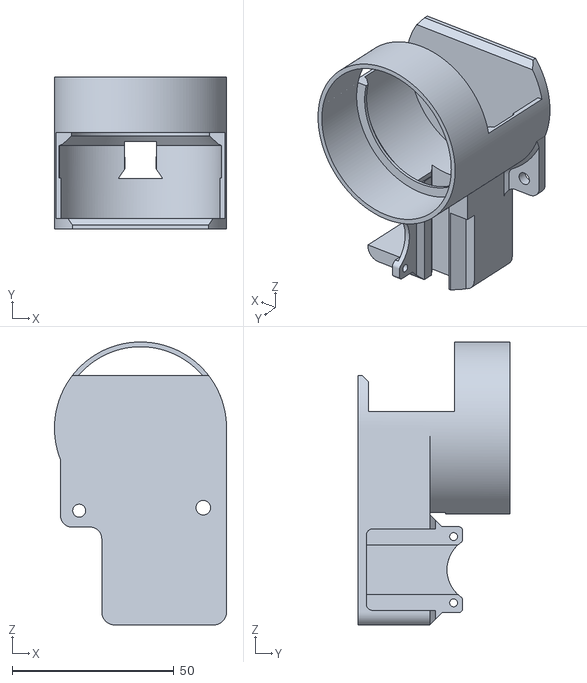
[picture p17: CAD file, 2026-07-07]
xiao-vending-machine-v0/xiao-vending-machine-assemble-steps/hardware-preparatory/stl-files/parts/dispenser.stl
53.2 x 47.1 x 87.5

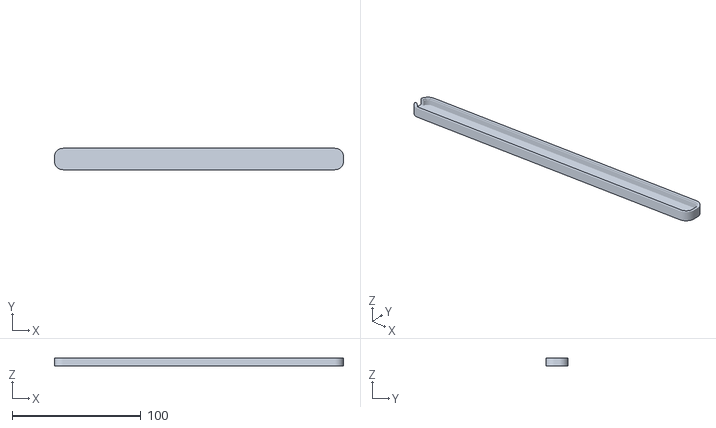
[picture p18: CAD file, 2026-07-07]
xiao-vending-machine-v0/xiao-vending-machine-assemble-steps/hardware-preparatory/stl-files/parts/LED holder .stl
224.5 x 16.7 x 6.50

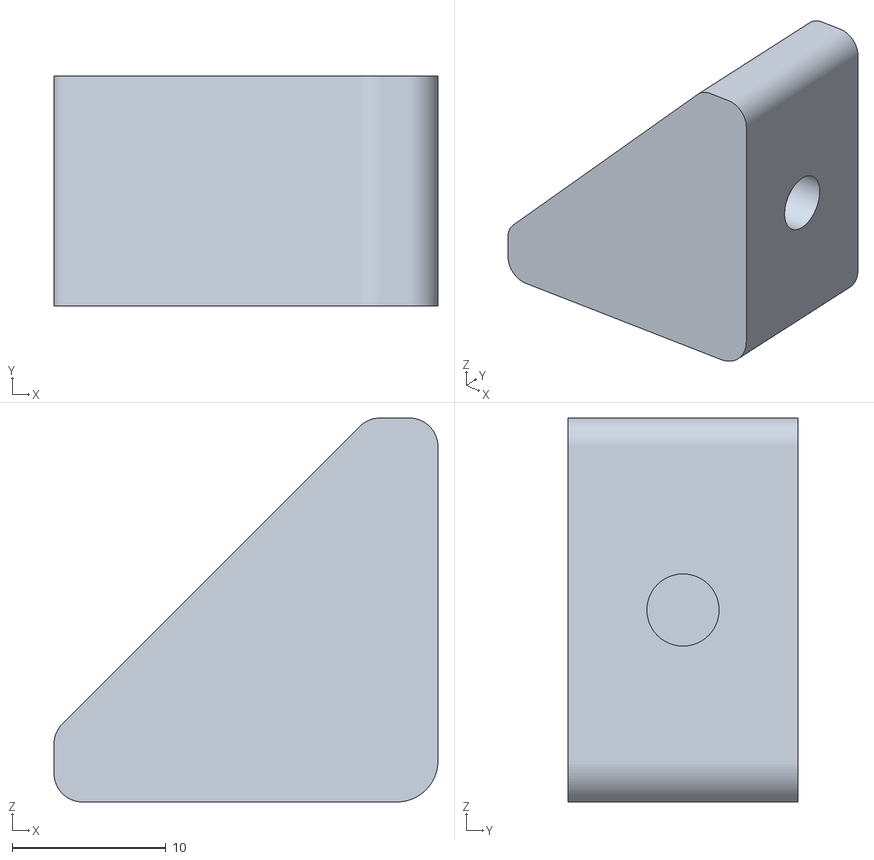
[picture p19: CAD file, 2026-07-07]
xiao-vending-machine-v0/xiao-vending-machine-assemble-steps/hardware-preparatory/stl-files/parts/L holder.stl
25.0 x 15.0 x 25.0

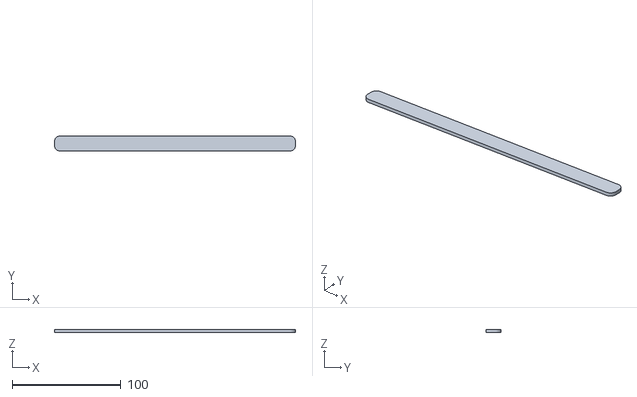
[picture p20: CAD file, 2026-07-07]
xiao-vending-machine-v0/xiao-vending-machine-assemble-steps/hardware-preparatory/stl-files/parts/LED diffuser.stl
221.5 x 13.8 x 2.56

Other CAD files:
xiao-vending-machine-v0/xiao-vending-machine-assemble-steps/hardware-preparatory/stl-files/parts/Pillar B.stl
xiao-vending-machine-v0/xiao-vending-machine-assemble-steps/hardware-preparatory/stl-files/parts/Spur Gear 24 teeth.stl
xiao-vending-machine-v0/xiao-vending-machine-assemble-steps/hardware-preparatory/stl-files/parts/dispenser arm.stl
xiao-vending-machine-v0/xiao-vending-machine-assemble-steps/hardware-preparatory/stl-files/parts/small feet .stl

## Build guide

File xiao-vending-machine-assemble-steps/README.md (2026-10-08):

# Xiao Vending Machine — Hardware & Assembly

*Print it, cut it, build it — the open-source hardware behind the [reference machine](../websites/en/index.html#reference).*

This guide covers the physical build: the parts you fabricate, and ten photographed steps from a single dispenser to the finished machine. The software that brings it to life — backend, dashboard, and firmware — lives in [`xiao-vending-machine-full-code-system/`](../xiao-vending-machine-full-code-system). For where this fits in the bigger picture, see [Journey](../websites/en/journey.html).

Photos, wiring diagram, and test videos live in [`assets/`](assets/).

## What you'll fabricate

Every design file is open and editable, so you can adapt a part before you make it. All files live under [`hardware-preparatory/stl-files/`](hardware-preparatory/stl-files).

### 3D-printed parts — [`parts/`](hardware-preparatory/stl-files/parts) (STL)

| Part | Quantity | Notes |
| --- | --- | --- |
| `dispenser.stl` | 4 | **Common** dispenser body — default for a standard product size |
| `dispenser-specific.stl` | 4 | **Product-specific** dispenser body — print this instead of `dispenser.stl` when adapting the mechanism for a different product geometry |
| `dispenser arm.stl` | 4 | |
| `Spur Gear 24 teeth.stl` | 1 | |
| `Tube support .stl` | 1 | |
| `Pillar A .stl` | 1 | |
| `Pillar B.stl` | 1 | |
| `L holder.stl` | 6 | |
| `slider_wio holder .stl` | 1 | |
| `RF ID cap .stl` | 1 | |
| `LED holder .stl` | 1 | |
| `LED diffuser.stl` | 1 | |
| `small feet .stl` | 4 | |

Print **either** `dispenser.stl` **or** `dispenser-specific.stl` for each column (four bodies total) — not both. Use the common body for the reference product; switch to the specific body when you redesign the dispenser for your own item.

### Case & structural parts — [`case/`](hardware-preparatory/stl-files/case) (STEP)

| Part | Quantity |
| --- | --- |
| `outer enclosure.step` | 1 |
| `top plate.step` | 1 |
| `back plate .step` | 1 |
| `lock holder.step` | 1 |
| `Mag plate.step` | 1 |

STEP files are editable CAD solids — adapt them, then export for your own printer, CNC, or laser cutter.

## What you'll buy

Off-the-shelf components and stock material to source separately. Every product link below is an **example** — any equivalent part works.

### Electronics & compute

Driven by the [code system](../xiao-vending-machine-full-code-system); wiring and flashing are covered there.

| Component | Qty | Notes | Example |
| --- | --- | --- | --- |
| Wio Terminal | 2 | Front reader (in the machine) + card writer (operator desk) | [Seeed Wio Terminal](https://www.seeedstudio.com/Wio-Terminal-p-4509.html) |
| Feetech ST3215 C044 bus servo | 4 | UART serial bus — one per dispensing column | [Seeed ST3215 C044](https://www.seeedstudio.com/Feetech-ST-3215-C044-Heavy-Duty-Servo-7-4V-1-191-Gear-Reduction-p-6460.html) |
| Grove NFC reader (I2C) | 1 | I2C RFID reader — Grove I2C (`Wire1`) on pins 27/28 | [Seeed Grove NFC ST25DV64](https://www.seeedstudio.com/Grove-NFC-ST25DV64KC-p-5688.html) |
| Grove 125KHz RFID reader (UART) | 1 | UART RFID reader — alternative interface | [Seeed Grove 125KHz RFID](https://www.seeedstudio.com/Grove-125KHz-RFID-Reader.html) |
| M1 RFID tag (13.56 MHz) | as needed | Works with either RFID reader above | [Seeed M1 RFID Tag](https://www.seeedstudio.com/M1-RFID-Tag-13-56MH-p-923.html) |

### Power

The machine needs one **12 V input** to power the servos and a **5 V USB input** to power the Wio Terminal. The 12 V 10 A adapter supplies the 12 V rail for the four servos; the buck converter steps that 12 V down to the 5 V USB that powers the Wio Terminal, so a single adapter runs everything.

| Component | Qty | Notes | Example |
| --- | --- | --- | --- |
| 12 V 10 A power adapter | 1 | 12 V input — powers the four bus servos | [Seeed FY1209900 12V 10A](https://www.seeedstudio.com/FY1209900-12V-10A-Power-Adapter-12V-10A-p-6496.html) |
| Buck converter (12 V/24 V → 5 V) | 1 | Steps 12 V down to the 5 V USB that powers the Wio Terminal | [Seeed CPT-C5 12V/24V→5V](https://www.seeedstudio.com/CPT-C5-power-converter-12V-24V-switch-to-5V.html) |

### Fasteners & mechanical hardware

| Component | Qty | Notes | Example |
| --- | --- | --- | --- |
| Hinge | 2 | Top lid — opens for refilling | [AliExpress](https://www.aliexpress.com/item/1005012567977773.html) |
| Lock | 1 | Top lid — secures the machine | [AliExpress](https://www.aliexpress.com/item/1005010288396245.html) |
| M3 injection-molded copper heat-set nut | as needed | Threaded inserts pressed into the printed parts | [AliExpress](https://www.aliexpress.com/item/1005006472962973.html) |
| M3×20 / M4×20 screw + nut kit | as needed | General assembly fixings | [AliExpress](https://www.aliexpress.com/item/1005005879037174.html) |

### Structural material

| Material | Qty | Notes |
| --- | --- | --- |
| PVC column | 4 | The four product columns (product tubes) |
| PC (polycarbonate) board | 1 | Front panel that carries the customer-facing Wio Terminal |

## Assembly, step by step

Each step pairs the CAD design with a photo of the real build.

### 1. The dispenser unit

Build one dispensing column: the dispenser body (`dispenser.stl` for the common / reference product, or `dispenser-specific.stl` when adapting for a different product), its arm, and the 24-tooth spur gear that a bus servo turns to release a single product.

| Design | Real build |
| --- | --- |
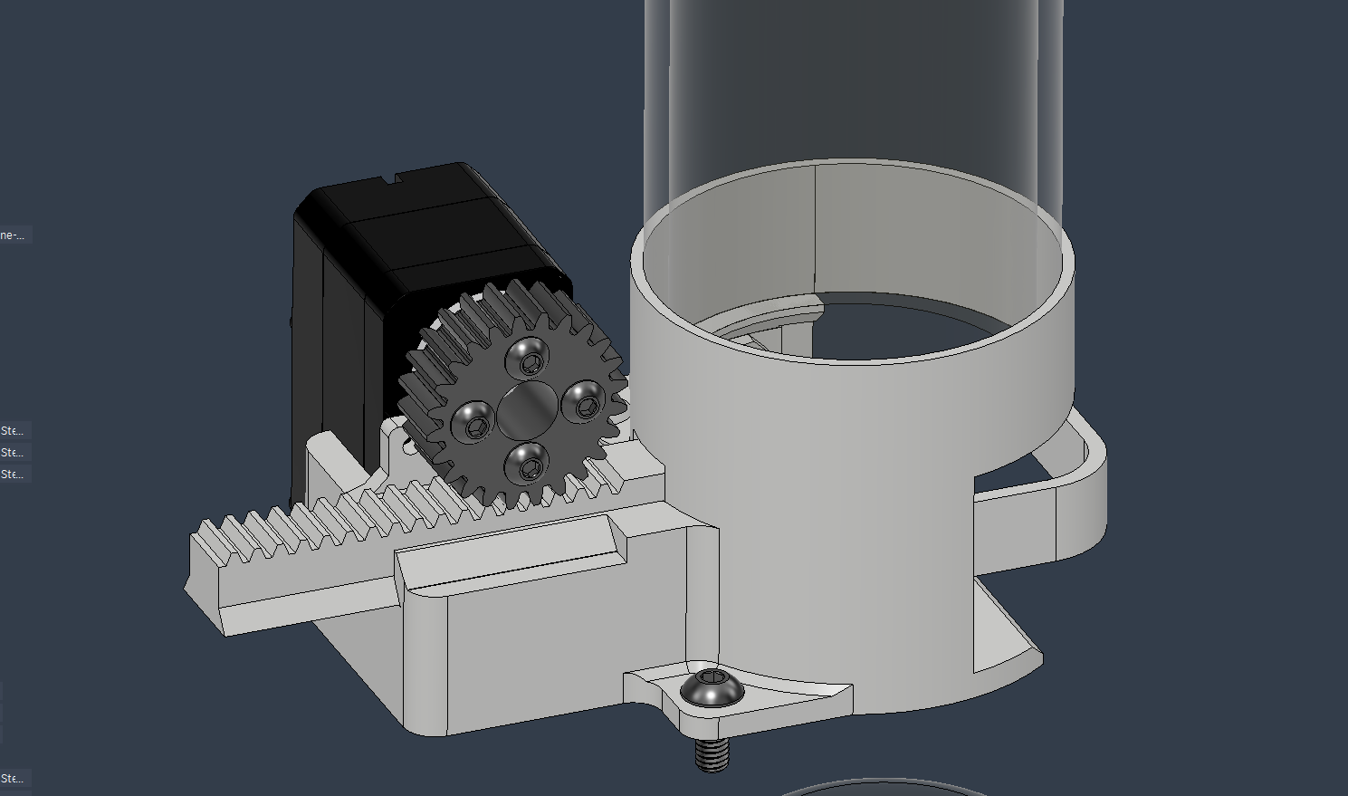
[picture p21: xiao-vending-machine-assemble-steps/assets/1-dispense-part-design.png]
Dispenser unit — design
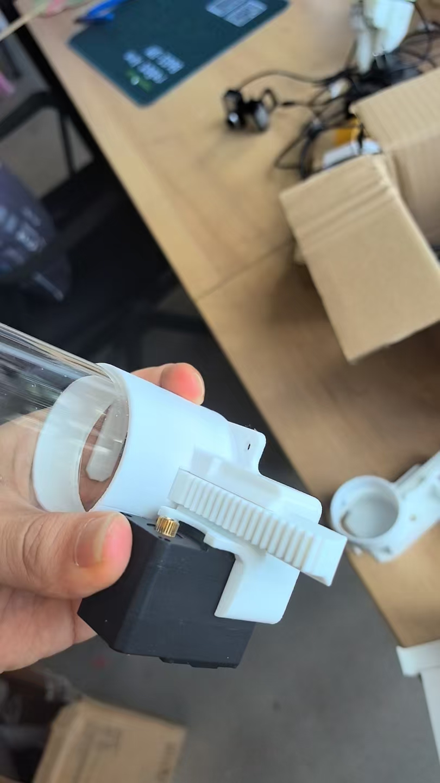
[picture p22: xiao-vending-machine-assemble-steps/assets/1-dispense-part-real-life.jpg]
Dispenser unit — real build
|  |  |

### 2. The full dispenser bank

Repeat the unit four times and tie them together with the tube support to form the four-column dispenser bank.

| Design | Real build |
| --- | --- |
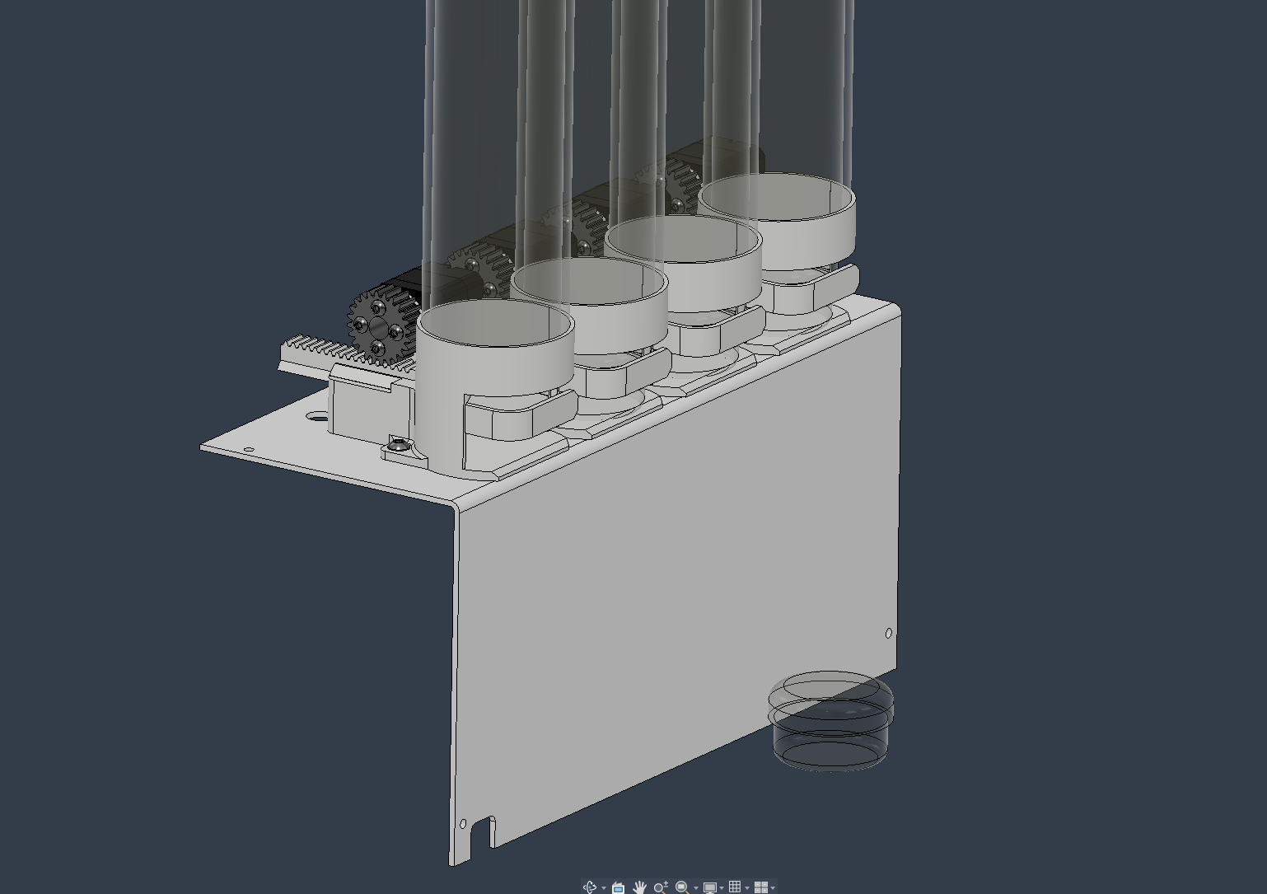
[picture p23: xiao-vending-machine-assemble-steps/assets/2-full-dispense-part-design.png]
Full dispenser bank — design
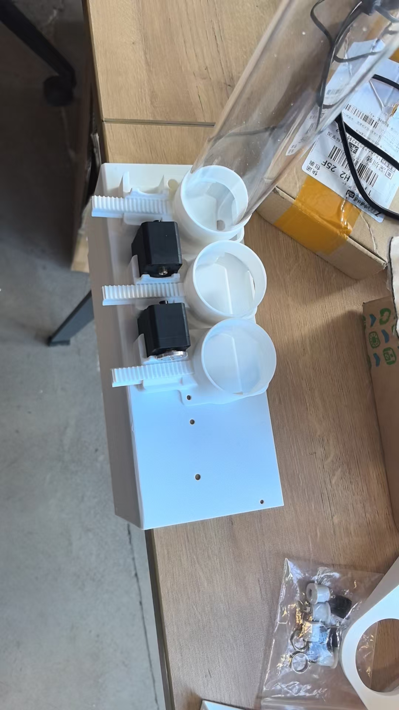
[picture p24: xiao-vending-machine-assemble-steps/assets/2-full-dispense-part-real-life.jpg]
Full dispenser bank — real build
|  |  |

### 3. Pillars A & B — the frame

Stand up Pillars A and B and join them with the L holders to form the machine's load-bearing skeleton.

| Design | Design (detail) | Real build |
| --- | --- | --- |
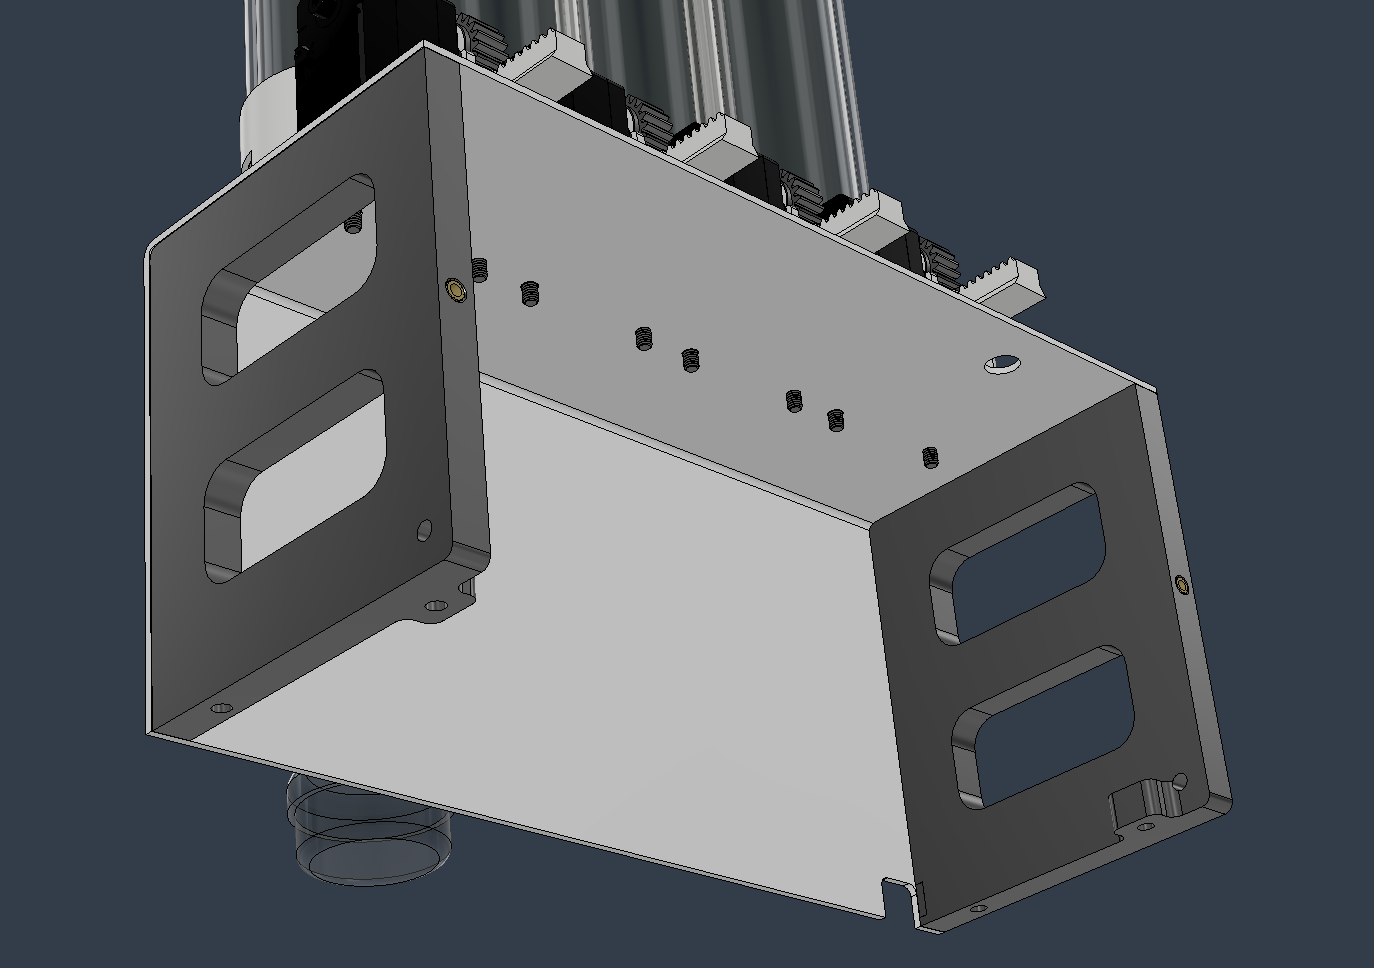
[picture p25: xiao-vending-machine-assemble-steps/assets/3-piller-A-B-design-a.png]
Pillars — design A
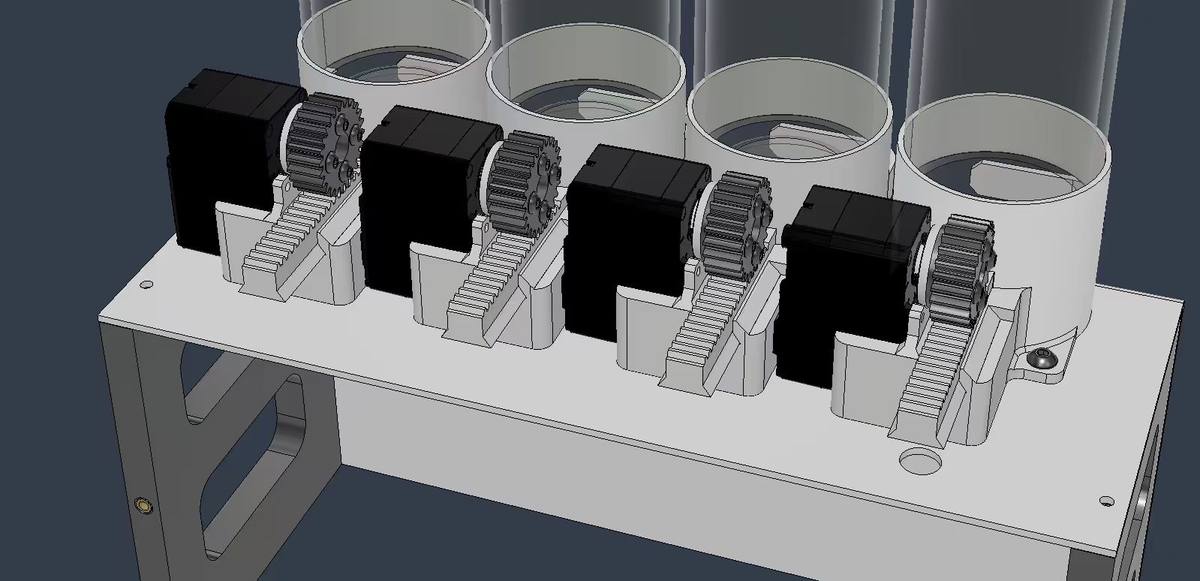
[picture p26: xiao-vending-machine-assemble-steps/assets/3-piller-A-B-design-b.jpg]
Pillars — design B
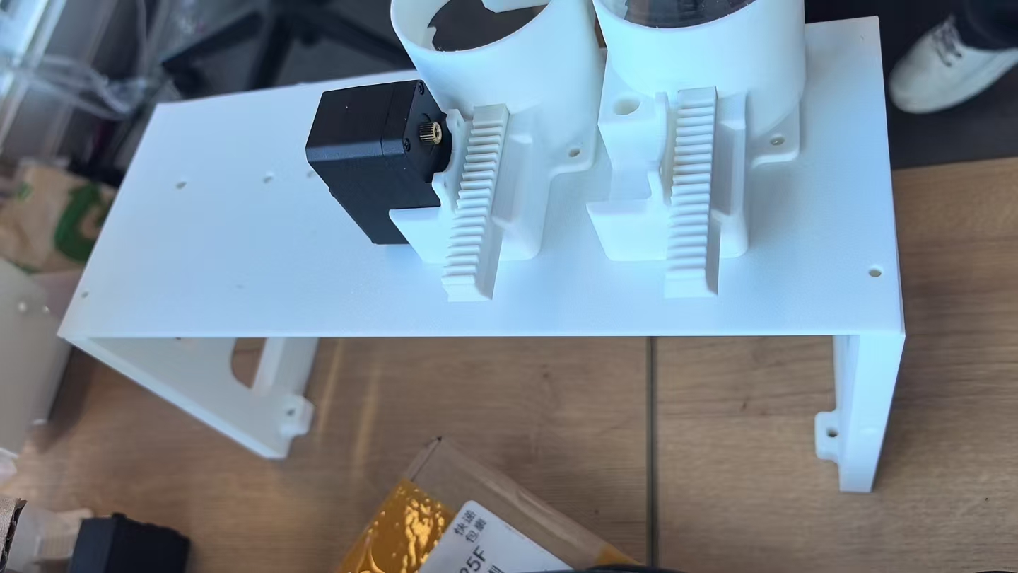
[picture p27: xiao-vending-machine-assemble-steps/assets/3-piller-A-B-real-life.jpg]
Pillars — real build
|  |  |  |

### 4. The back plate

Mount the back plate onto the frame to close and stiffen the rear of the machine.

| Design | Real build |
| --- | --- |
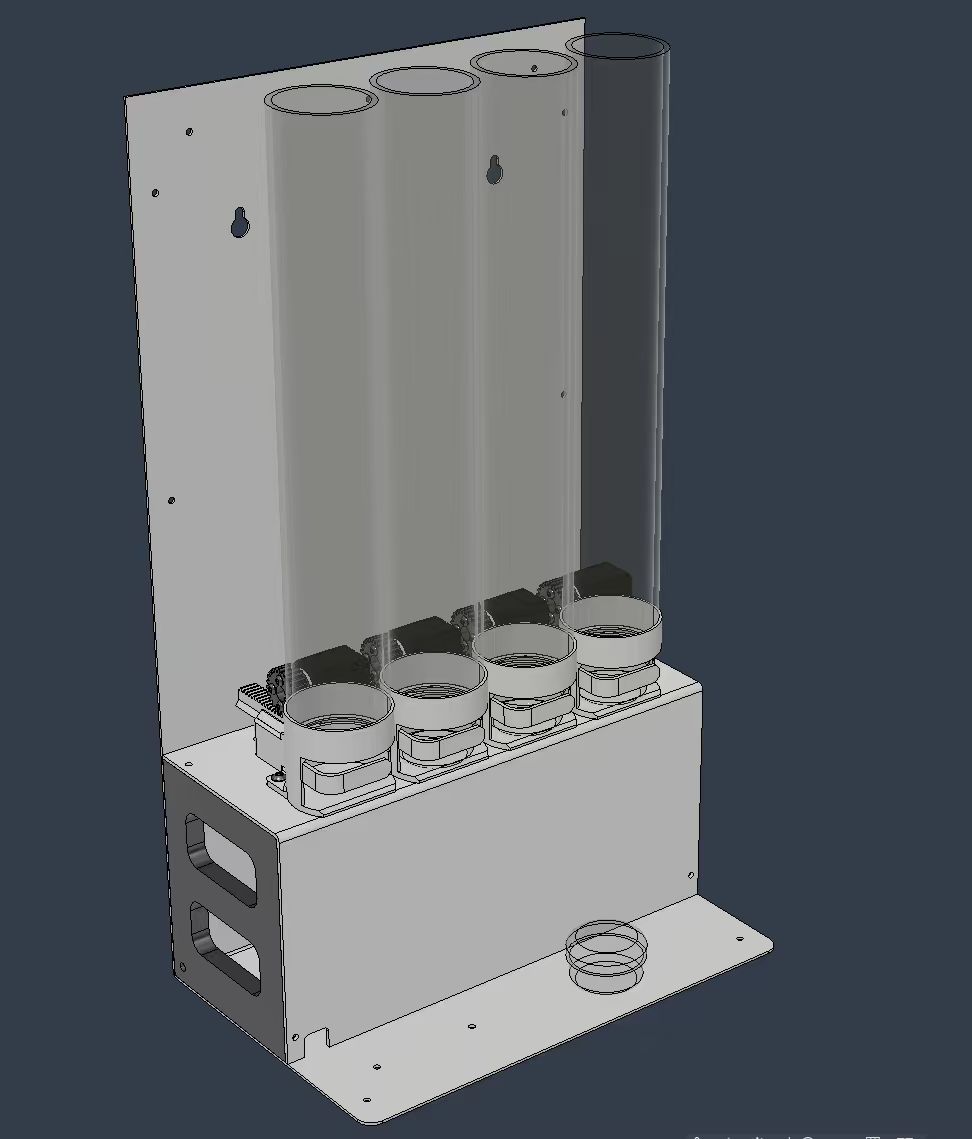
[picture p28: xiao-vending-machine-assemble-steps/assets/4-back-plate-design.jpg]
Back plate — design
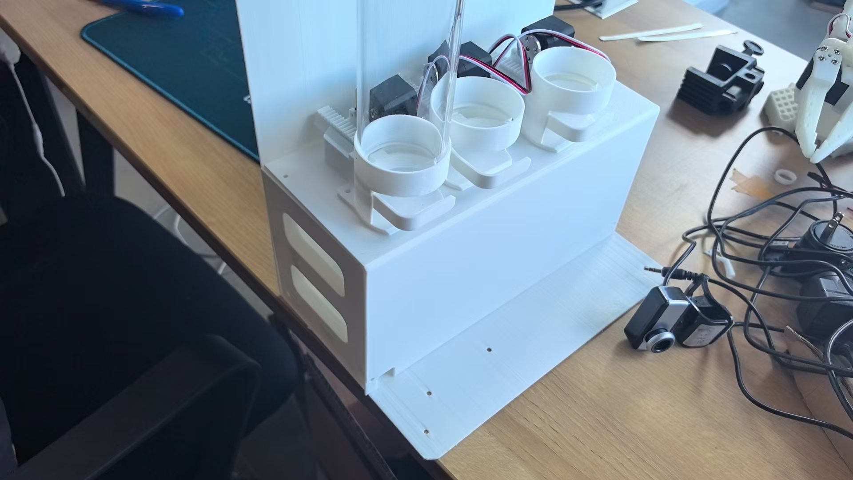
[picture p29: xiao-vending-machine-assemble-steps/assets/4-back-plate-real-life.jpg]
Back plate — real build
|  |  |

### 5. The slider & Wio holder

Fit the slider that carries and positions the customer-facing Wio Terminal.

| Design | Real build |
| --- | --- |
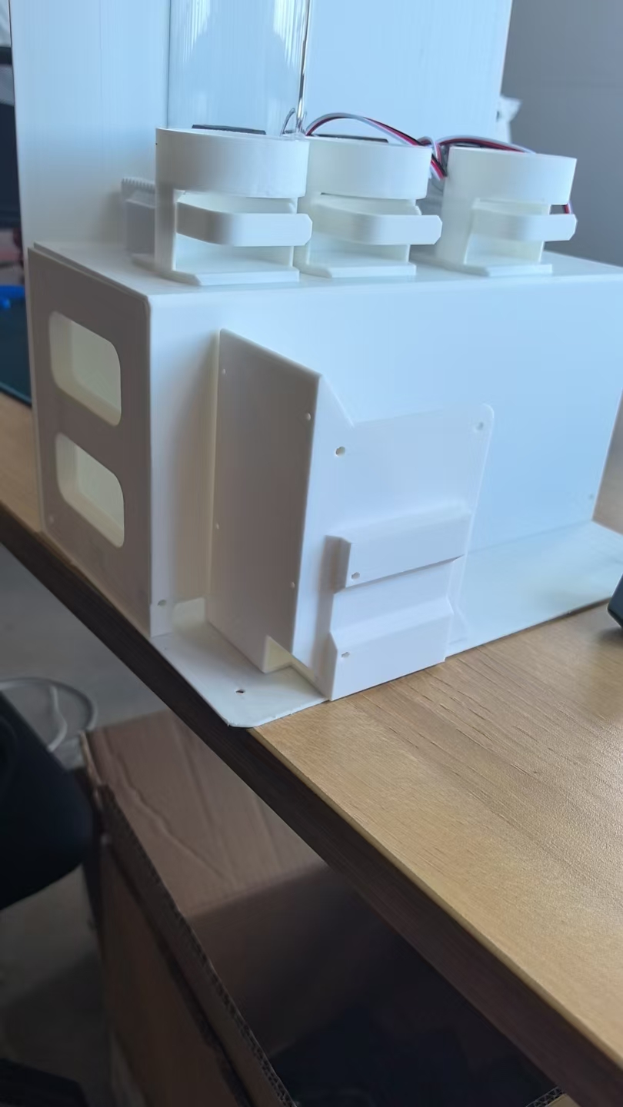
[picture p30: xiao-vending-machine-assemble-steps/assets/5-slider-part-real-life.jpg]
Slider — real build
| Slider — design |  |

### 6. The Wio Terminal & RFID reader

Install the front Wio Terminal and seat the RFID reader behind its cap, with the LED holder and diffuser for the status light.

| Design | Real build |
| --- | --- |
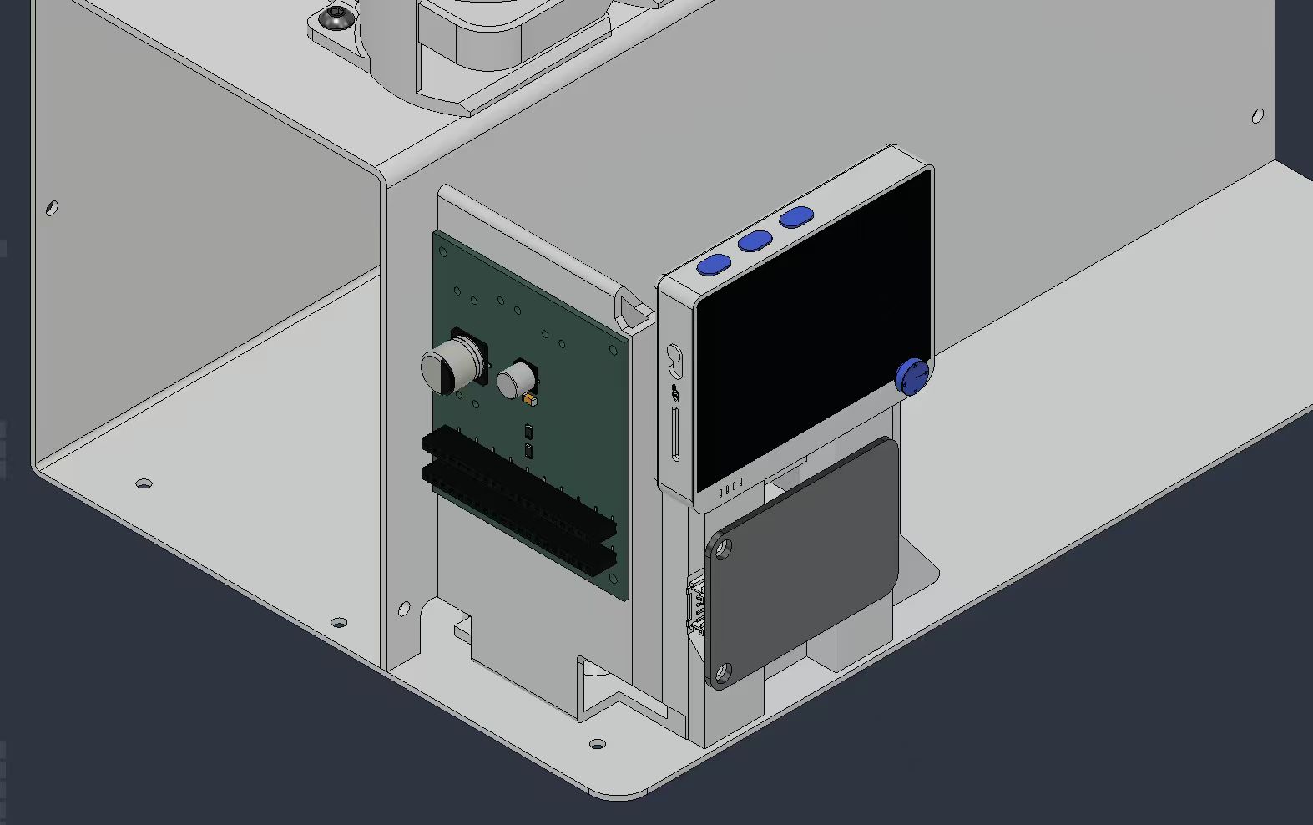
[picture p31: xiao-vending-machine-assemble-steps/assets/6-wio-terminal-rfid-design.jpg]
Wio Terminal and RFID — design
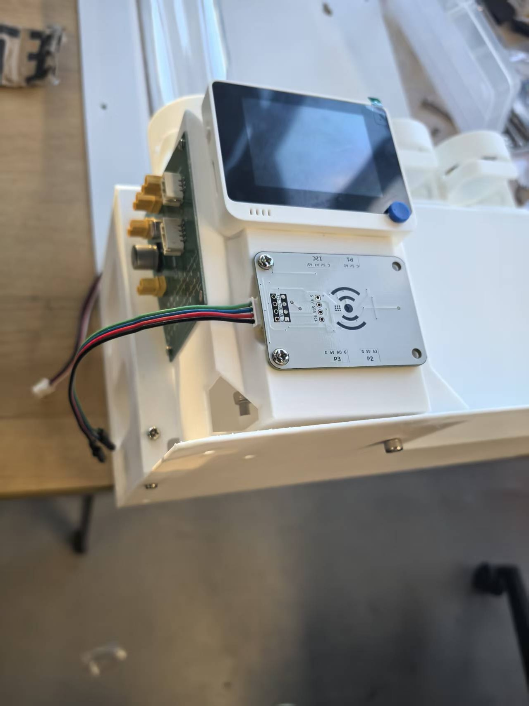
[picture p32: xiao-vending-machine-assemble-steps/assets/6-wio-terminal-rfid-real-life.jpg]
Wio Terminal and RFID — real build
|  |  |

### 7. The column tops

Cap the product columns with the top plate to guide and retain the stock.

| Design | Real build |
| --- | --- |
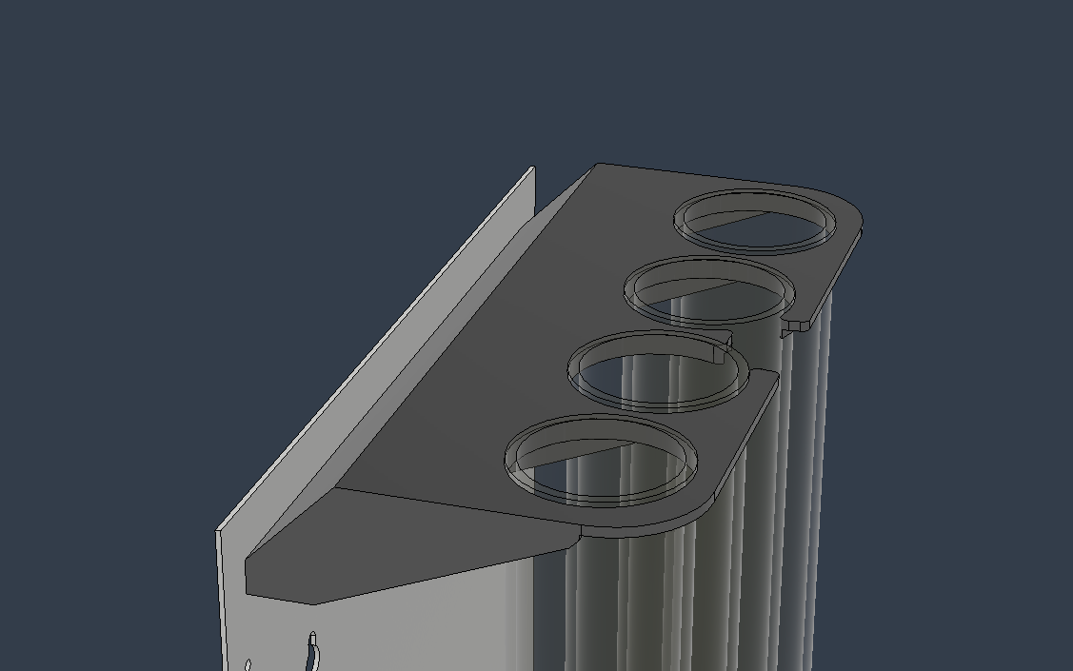
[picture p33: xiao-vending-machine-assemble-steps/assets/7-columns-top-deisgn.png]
Column tops — design
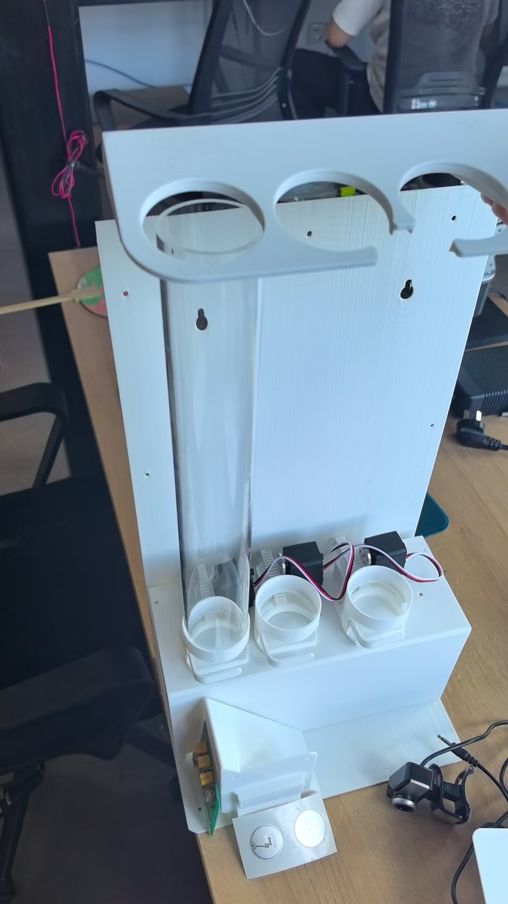
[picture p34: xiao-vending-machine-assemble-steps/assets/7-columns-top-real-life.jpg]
Column tops — real build
|  |  |

### 8. The outer enclosure

Wrap the build in the outer enclosure and add the four small feet.

| Design | Real build |
| --- | --- |
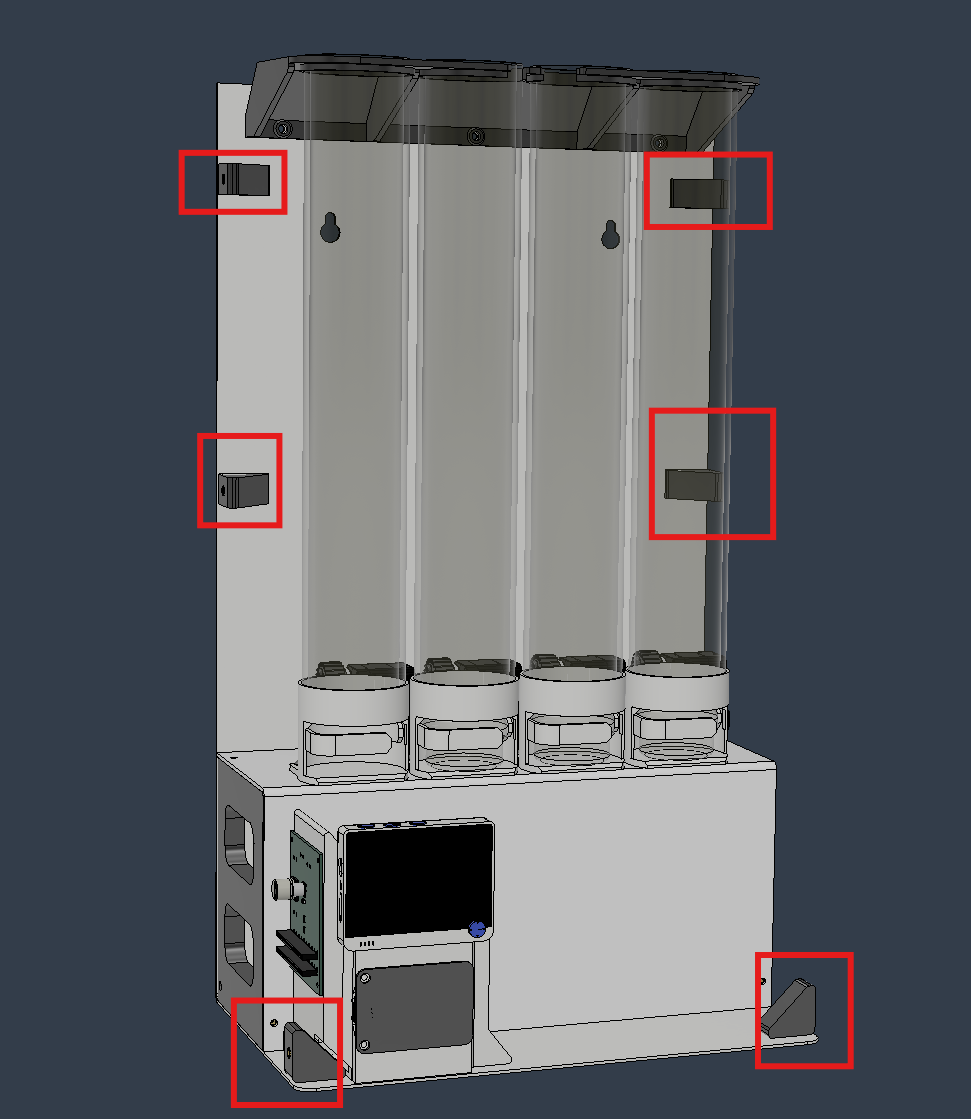
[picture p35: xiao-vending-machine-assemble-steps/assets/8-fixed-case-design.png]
Outer enclosure — design
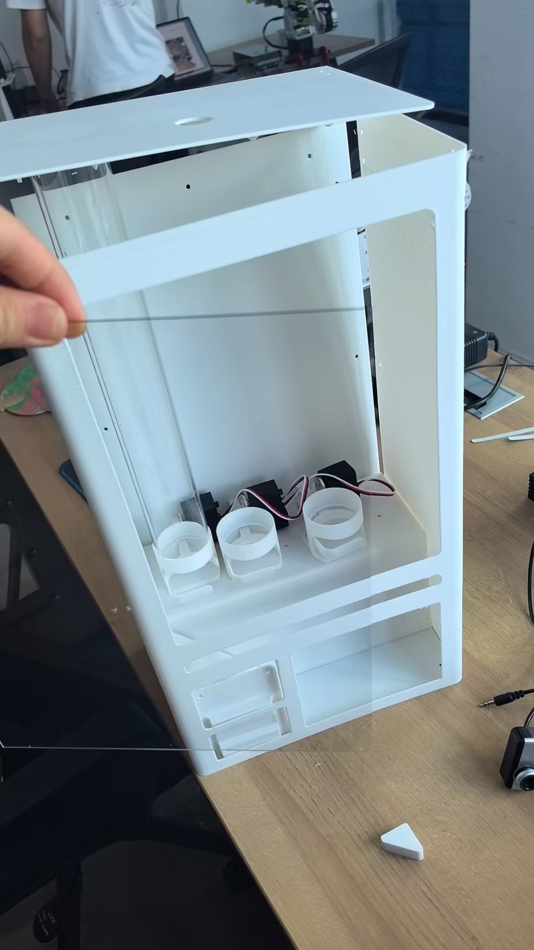
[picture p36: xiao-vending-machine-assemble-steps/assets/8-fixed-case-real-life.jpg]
Outer enclosure — real build
|  |  |

### 9. The top lock & hinge

Fit the lock holder and magnetic plate so the top opens for refilling and closes securely.

| Design | Real build |
| --- | --- |
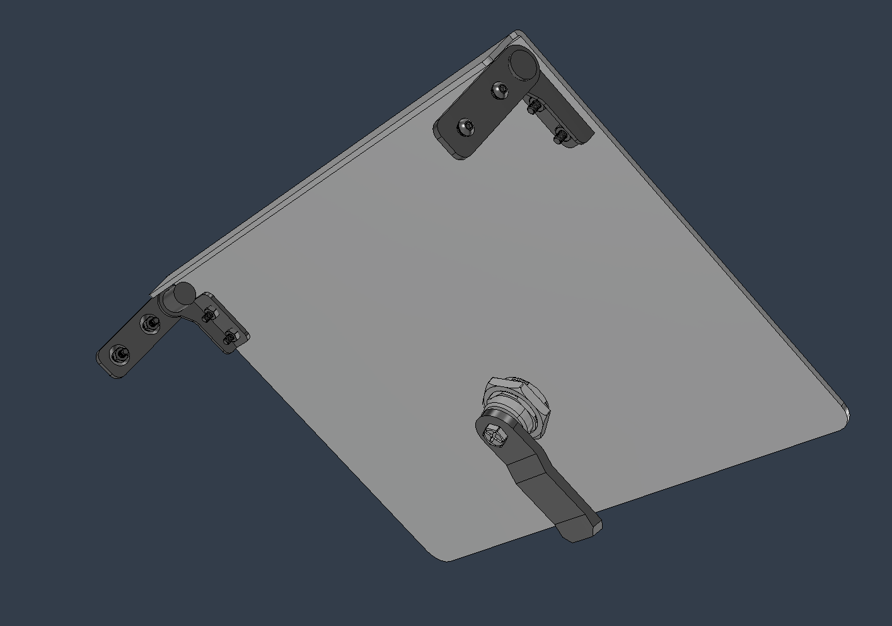
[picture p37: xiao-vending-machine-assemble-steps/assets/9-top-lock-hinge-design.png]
Top lock and hinge — design
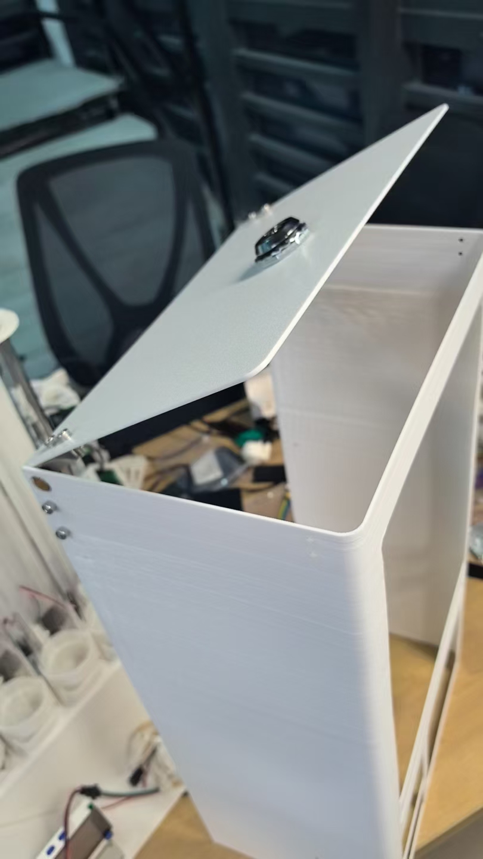
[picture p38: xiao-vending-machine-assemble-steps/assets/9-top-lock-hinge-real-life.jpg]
Top lock and hinge — real build
|  |  |

### 10. The finished machine

The completed, open-source Xiao vending machine — ready to load, flash, and run.

| Design | Real build |
| --- | --- |
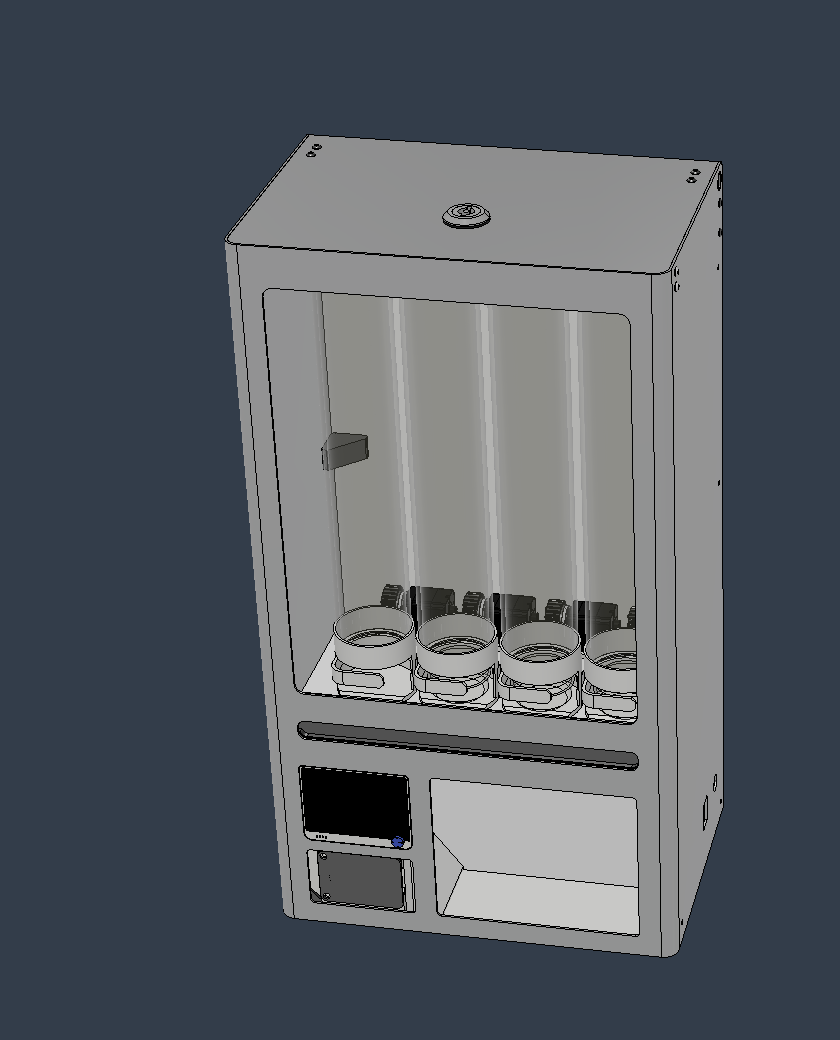
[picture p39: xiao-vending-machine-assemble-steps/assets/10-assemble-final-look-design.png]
Finished machine — design
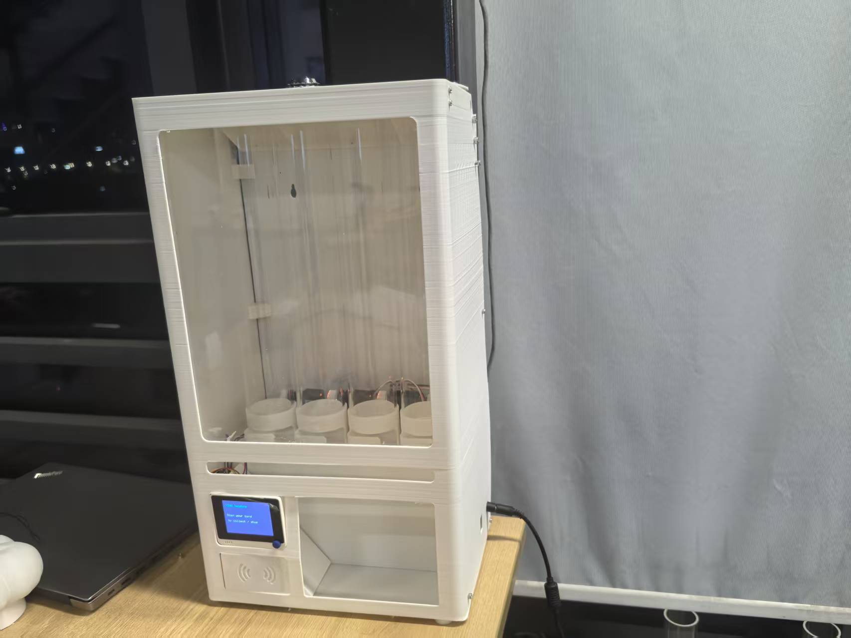
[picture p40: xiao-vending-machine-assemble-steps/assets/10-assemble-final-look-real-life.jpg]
Finished machine — real build
|  |  |

## Wio Terminal connection

The customer-facing Wio Terminal drives two peripherals through the 40-pin header on its back. Wire both before flashing the frontend firmware.

Wio Terminal wiring — servos and RFID

### Part 1 — Servo bus (UART)

The four Feetech serial servos share one UART bus. Connect the servo controller's **RX** to header pin **8 (TXD)** and **TX** to pin **10 (RXD)**. Share **GND** with the Wio (pin 9 or any GND).

### Part 2 — RFID reader

Use either RFID reader above — the M1 tags work with both. For the **I2C** reader (Grove NFC), connect **SDA** to pin **27**, **SCL** to pin **28**, **5V** to pin **2**, and **GND** to pin **9**. For the **UART** reader (Grove 125KHz), wire per its datasheet to the Wio's UART pins.

Both peripherals must be on the same Wio Terminal that runs [`official_frontend_wio_terminal`](../xiao-vending-machine-full-code-system/frontend-vending-machine/official_frontend_wio_terminal). The second Wio Terminal is the operator-side **card writer** — it only needs WiFi to the backend and its own RFID module; flash it from the [Config page](../xiao-vending-machine-full-code-system/backend-full/public/config.html).

## Testing phase — dispense modes

After hardware assembly and software bring-up, verify both customer flows on the finished machine. These recordings show the reference machine running the official firmware and backend.

### Direct dispensing

A **direct-order card** carries a fixed product list. The customer taps the card and the machine dispenses every item on it in one pass.

Direct dispensing test

[Full recording with sound (MP4)](https://raw.githubusercontent.com/Seeed-Studio/how-to-vend-almost-anything/main/xiao-vending-machine-assemble-steps/assets/direct-dispense-testing.mp4)

### Balance dispensing

A **selecting balance card** stores a customer name and stored value. The customer picks products on the Wio Terminal joystick until the balance is spent.

Balance dispensing test

[Full recording with sound (MP4)](https://raw.githubusercontent.com/Seeed-Studio/how-to-vend-almost-anything/main/xiao-vending-machine-assemble-steps/assets/balance-dispense-testing.mp4)

For the incremental bring-up path before this end-to-end test, see [`testing_phase/`](../xiao-vending-machine-full-code-system/frontend-vending-machine/testing_phase) in the code system.

## Next: bring it to life

With the hardware assembled, install the software and flash the two Wio Terminals following [`xiao-vending-machine-full-code-system/`](../xiao-vending-machine-full-code-system) and [Journey](../websites/en/journey.html).

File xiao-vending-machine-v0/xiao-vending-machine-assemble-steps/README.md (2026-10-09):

# Xiao Vending Machine — Hardware & Assembly

*Print it, cut it, build it — the open-source hardware behind the [reference machine](../../docs/en/index.html#reference).*

This guide covers the physical build: the parts you fabricate, and ten photographed steps from a single dispenser to the finished machine. The software that brings it to life — backend, dashboard, and firmware — lives in [`xiao-vending-machine-full-code-system/`](../xiao-vending-machine-full-code-system). For where this fits in the bigger picture, see [Journey](../../docs/en/journey.html).

Photos, wiring diagram, and test videos live in [`assets/`](assets/).

## What you'll fabricate

Every design file is open and editable, so you can adapt a part before you make it. All files live under [`hardware-preparatory/stl-files/`](hardware-preparatory/stl-files).

### 3D-printed parts — [`parts/`](hardware-preparatory/stl-files/parts) (STL)

| Part | Quantity | Notes |
| --- | --- | --- |
| `dispenser.stl` | 4 | **Common** dispenser body — default for a standard product size |
| `dispenser-specific.stl` | 4 | **Product-specific** dispenser body — print this instead of `dispenser.stl` when adapting the mechanism for a different product geometry |
| `dispenser arm.stl` | 4 | |
| `Spur Gear 24 teeth.stl` | 1 | |
| `Tube support .stl` | 1 | |
| `Pillar A .stl` | 1 | |
| `Pillar B.stl` | 1 | |
| `L holder.stl` | 6 | |
| `slider_wio holder .stl` | 1 | |
| `RF ID cap .stl` | 1 | |
| `LED holder .stl` | 1 | |
| `LED diffuser.stl` | 1 | |
| `small feet .stl` | 4 | |

Print **either** `dispenser.stl` **or** `dispenser-specific.stl` for each column (four bodies total) — not both. Use the common body for the reference product; switch to the specific body when you redesign the dispenser for your own item.

### Case & structural parts — [`case/`](hardware-preparatory/stl-files/case) (STEP)

| Part | Quantity |
| --- | --- |
| `outer enclosure.step` | 1 |
| `top plate.step` | 1 |
| `back plate .step` | 1 |
| `lock holder.step` | 1 |
| `Mag plate.step` | 1 |

STEP files are editable CAD solids — adapt them, then export for your own printer, CNC, or laser cutter.

## What you'll buy

Off-the-shelf components and stock material to source separately. Every product link below is an **example** — any equivalent part works.

### Electronics & compute

Driven by the [code system](../xiao-vending-machine-full-code-system); wiring and flashing are covered there.

| Component | Qty | Notes | Example |
| --- | --- | --- | --- |
| Wio Terminal | 2 | Front reader (in the machine) + card writer (operator desk) | [Seeed Wio Terminal](https://www.seeedstudio.com/Wio-Terminal-p-4509.html) |
| Feetech ST3215 C044 bus servo | 4 | UART serial bus — one per dispensing column | [Seeed ST3215 C044](https://www.seeedstudio.com/Feetech-ST-3215-C044-Heavy-Duty-Servo-7-4V-1-191-Gear-Reduction-p-6460.html) |
| Grove NFC reader (I2C) | 1 | I2C RFID reader — Grove I2C (`Wire1`) on pins 27/28 | [Seeed Grove NFC ST25DV64](https://www.seeedstudio.com/Grove-NFC-ST25DV64KC-p-5688.html) |
| Grove 125KHz RFID reader (UART) | 1 | UART RFID reader — alternative interface | [Seeed Grove 125KHz RFID](https://www.seeedstudio.com/Grove-125KHz-RFID-Reader.html) |
| M1 RFID tag (13.56 MHz) | as needed | Works with either RFID reader above | [Seeed M1 RFID Tag](https://www.seeedstudio.com/M1-RFID-Tag-13-56MH-p-923.html) |

### Power

The machine needs one **12 V input** to power the servos and a **5 V USB input** to power the Wio Terminal. The 12 V 10 A adapter supplies the 12 V rail for the four servos; the buck converter steps that 12 V down to the 5 V USB that powers the Wio Terminal, so a single adapter runs everything.

| Component | Qty | Notes | Example |
| --- | --- | --- | --- |
| 12 V 10 A power adapter | 1 | 12 V input — powers the four bus servos | [Seeed FY1209900 12V 10A](https://www.seeedstudio.com/FY1209900-12V-10A-Power-Adapter-12V-10A-p-6496.html) |
| Buck converter (12 V/24 V → 5 V) | 1 | Steps 12 V down to the 5 V USB that powers the Wio Terminal | [Seeed CPT-C5 12V/24V→5V](https://www.seeedstudio.com/CPT-C5-power-converter-12V-24V-switch-to-5V.html) |

### Fasteners & mechanical hardware

| Component | Qty | Notes | Example |
| --- | --- | --- | --- |
| Hinge | 2 | Top lid — opens for refilling | [AliExpress](https://www.aliexpress.com/item/1005012567977773.html) |
| Lock | 1 | Top lid — secures the machine | [AliExpress](https://www.aliexpress.com/item/1005010288396245.html) |
| M3 injection-molded copper heat-set nut | as needed | Threaded inserts pressed into the printed parts | [AliExpress](https://www.aliexpress.com/item/1005006472962973.html) |
| M3×20 / M4×20 screw + nut kit | as needed | General assembly fixings | [AliExpress](https://www.aliexpress.com/item/1005005879037174.html) |

### Structural material

| Material | Qty | Notes |
| --- | --- | --- |
| PVC column | 4 | The four product columns (product tubes) |
| PC (polycarbonate) board | 1 | Front panel that carries the customer-facing Wio Terminal |

## Assembly, step by step

Each step pairs the CAD design with a photo of the real build.

### 1. The dispenser unit

Build one dispensing column: the dispenser body (`dispenser.stl` for the common / reference product, or `dispenser-specific.stl` when adapting for a different product), its arm, and the 24-tooth spur gear that a bus servo turns to release a single product.

| Design | Real build |
| --- | --- |
| Dispenser unit — design | Dispenser unit — real build |

### 2. The full dispenser bank

Repeat the unit four times and tie them together with the tube support to form the four-column dispenser bank.

| Design | Real build |
| --- | --- |
| Full dispenser bank — design | Full dispenser bank — real build |

### 3. Pillars A & B — the frame

Stand up Pillars A and B and join them with the L holders to form the machine's load-bearing skeleton.

| Design | Design (detail) | Real build |
| --- | --- | --- |
| Pillars — design A | Pillars — design B | Pillars — real build |

### 4. The back plate

Mount the back plate onto the frame to close and stiffen the rear of the machine.

| Design | Real build |
| --- | --- |
| Back plate — design | Back plate — real build |

### 5. The slider & Wio holder

Fit the slider that carries and positions the customer-facing Wio Terminal.

| Design | Real build |
| --- | --- |
| Slider — design | Slider — real build |

### 6. The Wio Terminal & RFID reader

Install the front Wio Terminal and seat the RFID reader behind its cap, with the LED holder and diffuser for the status light.

| Design | Real build |
| --- | --- |
| Wio Terminal and RFID — design | Wio Terminal and RFID — real build |

### 7. The column tops

Cap the product columns with the top plate to guide and retain the stock.

| Design | Real build |
| --- | --- |
| Column tops — design | Column tops — real build |

### 8. The outer enclosure

Wrap the build in the outer enclosure and add the four small feet.

| Design | Real build |
| --- | --- |
| Outer enclosure — design | Outer enclosure — real build |

### 9. The top lock & hinge

Fit the lock holder and magnetic plate so the top opens for refilling and closes securely.

| Design | Real build |
| --- | --- |
| Top lock and hinge — design | Top lock and hinge — real build |

### 10. The finished machine

The completed, open-source Xiao vending machine — ready to load, flash, and run.

| Design | Real build |
| --- | --- |
| Finished machine — design | Finished machine — real build |

## Wio Terminal connection

The customer-facing Wio Terminal drives two peripherals through the 40-pin header on its back. Wire both before flashing the frontend firmware.

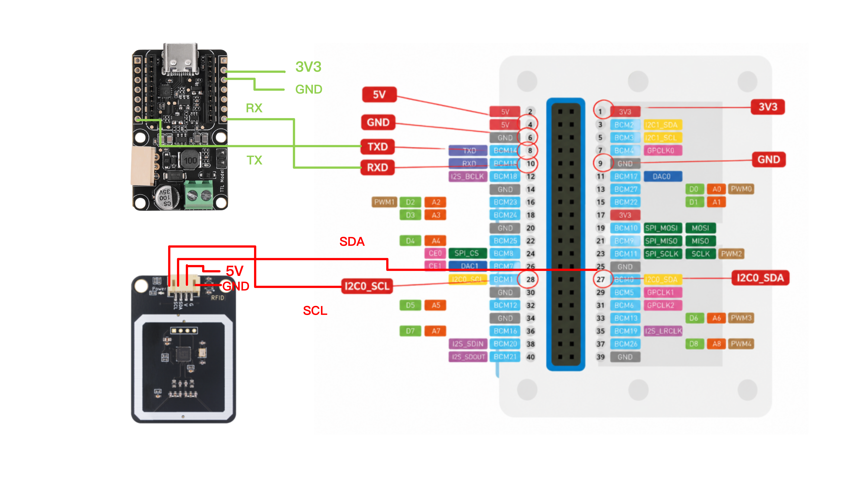
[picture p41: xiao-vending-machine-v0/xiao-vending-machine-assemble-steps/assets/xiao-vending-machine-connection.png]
Wio Terminal wiring — servos and RFID


### Part 1 — Servo bus (UART)

The four Feetech serial servos share one UART bus. Connect the servo controller's **RX** to header pin **8 (TXD)** and **TX** to pin **10 (RXD)**. Share **GND** with the Wio (pin 9 or any GND).

### Part 2 — RFID reader

Use either RFID reader above — the M1 tags work with both. For the **I2C** reader (Grove NFC), connect **SDA** to pin **27**, **SCL** to pin **28**, **5V** to pin **2**, and **GND** to pin **9**. For the **UART** reader (Grove 125KHz), wire per its datasheet to the Wio's UART pins.

Both peripherals must be on the same Wio Terminal that runs [`official_frontend_wio_terminal`](../xiao-vending-machine-full-code-system/frontend-vending-machine/official_frontend_wio_terminal). The second Wio Terminal is the operator-side **card writer** — it only needs WiFi to the backend and its own RFID module; flash it from the [Config page](../xiao-vending-machine-full-code-system/backend-full/public/config.html).

## Testing phase — dispense modes

After hardware assembly and software bring-up, verify both customer flows on the finished machine. These recordings show the reference machine running the official firmware and backend.

### Direct dispensing

A **direct-order card** carries a fixed product list. The customer taps the card and the machine dispenses every item on it in one pass.

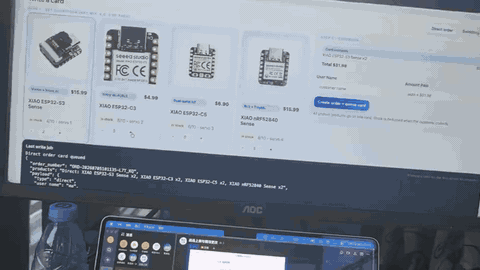
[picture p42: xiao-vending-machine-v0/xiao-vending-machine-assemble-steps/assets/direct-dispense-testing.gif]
Direct dispensing test


[Full recording with sound (MP4)](https://raw.githubusercontent.com/Seeed-Studio/how-to-vend-almost-anything/site/fab-vending-pages/xiao-vending-machine-v0/xiao-vending-machine-assemble-steps/assets/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)

### Balance dispensing

A **selecting balance card** stores a customer name and stored value. The customer picks products on the Wio Terminal joystick until the balance is spent.

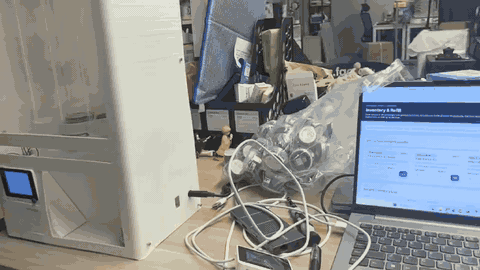
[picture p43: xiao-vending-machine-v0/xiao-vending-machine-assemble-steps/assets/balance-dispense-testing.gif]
Balance dispensing test


[Full recording with sound (MP4)](https://raw.githubusercontent.com/Seeed-Studio/how-to-vend-almost-anything/site/fab-vending-pages/xiao-vending-machine-v0/xiao-vending-machine-assemble-steps/assets/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)

For the incremental bring-up path before this end-to-end test, see [`testing_phase/`](../xiao-vending-machine-full-code-system/frontend-vending-machine/testing_phase) in the code system.

## Next: bring it to life

With the hardware assembled, install the software and flash the two Wio Terminals following [`xiao-vending-machine-full-code-system/`](../xiao-vending-machine-full-code-system) and [Journey](../../docs/en/journey.html).

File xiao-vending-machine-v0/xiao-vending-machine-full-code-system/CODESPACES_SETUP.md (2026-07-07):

# GitHub Codespaces setup

This project is prepared to run the backend in GitHub Codespaces.

## Start backend

In Codespaces terminal:

```bash
cd backend-full
npm start
```

## Make port 3000 public

1. Open the **Ports** tab in Codespaces.
2. Find port **3000**.
3. Right-click the port row.
4. Set **Port Visibility** to **Public**.
5. Copy the forwarded URL.

The URL will look like:

```text
https://something-3000.app.github.dev
```

## Test

Open:

```text
https://YOUR-CODESPACE-URL/api/health
```

Expected response:

```json
{"ok":true,"service":"backend-center","time":"..."}
```

## Wio setting

Put the copied Codespaces URL into the Wio sketch:

```cpp
const char* BACKEND_BASE_URL = "https://YOUR-CODESPACE-URL";
```

Do not add a slash at the end.

## Important

The Codespaces URL only works while the Codespace is running. If the Codespace stops, the Wio cannot reach the backend.

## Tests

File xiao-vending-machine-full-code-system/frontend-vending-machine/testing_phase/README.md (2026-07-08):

# Wio Terminal Test Phase

Incremental hardware bring-up tests for the Wio Terminal vending-machine
front end. Each test builds on the previous one, so run them in order:

| # | Folder | Adds | What it proves |
|---|---|---|---|
| 1-a | [`1-a-servo-locate/`](1-a-servo-locate/) | jog + capture | Find each servo's ZERO + MAX (8 numbers) with buttons/joystick |
| 1-b | [`1-b-servo-zero-porint/`](1-b-servo-zero-porint/) | home + range test | Home all servos to ZERO and verify the MAX travel from 1-a |
| 2 | [`2-servo-rfid-testing/`](2-servo-rfid-testing/) | + Emakefun RFID | Write Matthew/Alice cards, then read one and dispense per card |
| 3 (PC) | [`3-backend-wifi-testing/`](3-backend-wifi-testing/) | + Node backend | PC server: prints its IP, verifies a card (`true`/`false`), logs the dispense report |
| 3 (Wio) | [`3-wio-terminal-wifi-testing/`](3-wio-terminal-wifi-testing/) | + WiFi | Test 2 + WiFi: each read is verified by the backend, then reports what it dispensed |

Tests `1-a` and `1-b` are the servo calibration pair: `1-a` is an
interactive tool that finds, for every servo, its zero (home) station and
its maximum travel, then prints the 8 numbers; `1-b` takes those 8 numbers
and drives the servos to zero and back out to max to confirm the range.

Phase 3 is a **pair** that runs together: the PC backend
`3-backend-wifi-testing` and the Wio sketch `3-wio-terminal-wifi-testing`
(start the backend first, then point the Wio's `BACKEND_BASE` at it).

After the full stack is running on the assembled machine, see the end-to-end
**[direct dispensing](../../xiao-vending-machine-assemble-steps/README.md#testing-phase--dispense-modes)** and
**[balance dispensing](../../xiao-vending-machine-assemble-steps/README.md#testing-phase--dispense-modes)** test videos in the assembly guide.

The original single-sketch demos are kept for reference as
`1-servo-testing-non-used/` and `3-servero-rfid-wifi-testing-non-used/`.
Other helpers live alongside: `0-servo-set-id`, `servo-id-scan`,
`servo-diagnose`, `i2c-scan`, `card-writer`, `blank`.

The Wio sketches copy in the servo library files (`SCServo.h`, `SMS_STS.*`,
`SCSCL.*`, `SCS.*`, `SCSerial.*`, `INST.h`) and the RFID library files
(`Emakefun_RFID.*`) so every sketch compiles on its own. The backend is
plain Node.js with no dependencies.

## The servo motion

Serial servo positions are `0..4095` over 360 degrees, so 90 degrees is
1024 units.

- The original **`*-non-used`** demos run a 4-phase sweep: a "phase" moves
  servos `1..N` by +90 degrees, holds, then returns home (~2s), defaulting
  to `POS_HOME = 2048` / `POS_90 = 3072`.

  ```
  Phase 1 -> servo 1
  Phase 2 -> servos 1,2
  Phase 3 -> servos 1,2,3
  Phase 4 -> servos 1,2,3,4
  ```

- **Tests 1-a, 1-b, 2 and 3 (Wio)** use per-servo calibrated positions
  instead: a `ZERO` (home) and a `MAX`, found with `1-a-servo-locate`. One
  "dispense" is a full `ZERO -> MAX -> ZERO` sweep for a servo.

## The RFID card data

Tests 2 and 3 write and read their **own** cards (no external writer
needed) on MIFARE Classic blocks `4,5,6,8,9,10` with the default key
`FF FF FF FF FF FF`. Button A/B write these, button C reads them:

```jsonc
{"name":"Matthew","card":{"type":"balance"}}   // A -> joystick selection
{"name":"Alice","card":{"type":"prepaid"}}     // B -> fixed recipe
```

Test 3 additionally sends `{name, type}` to the backend and only dispenses
if it replies `true`. (The archived `3-servero-rfid-wifi-testing-non-used`
instead used the old `backend-full/wio-rfid-writer` payload
`{"user_name":...,"order_number":...}`.)

## Arduino CLI (one-time setup)

```bash
arduino-cli config init
arduino-cli config add board_manager.additional_urls https://files.seeedstudio.com/arduino/package_seeeduino_boards_index.json
arduino-cli core update-index
arduino-cli core install Seeeduino:samd
```

Compile + upload a test (replace the port with yours from
`arduino-cli board list`; on macOS it looks like `/dev/cu.usbmodemXXXX`):

```bash
cd 1-a-servo-locate
arduino-cli compile --fqbn Seeeduino:samd:seeed_wio_terminal .
arduino-cli upload -p /dev/cu.usbmodemXXXX --fqbn Seeeduino:samd:seeed_wio_terminal .
```

The phase-3 Wio sketch also needs the **Seeed Arduino rpcWiFi** library.
Its PC backend is not an Arduino sketch - run it with Node:

```bash
cd 3-backend-wifi-testing
sudo node server.js     # port 80; or: PORT=8080 node server.js
```

## Note on the folder names

The folders start with a digit and use hyphens (for example
`1-a-servo-locate`). Each `.ino` is named identically to its folder, which
is what `arduino-cli` needs. If the Arduino IDE ever complains about the
name, open the `.ino` file directly or rename the folder + sketch
together.

The folder/sketch name `1-b-servo-zero-porint` keeps its original spelling
(`porint`).

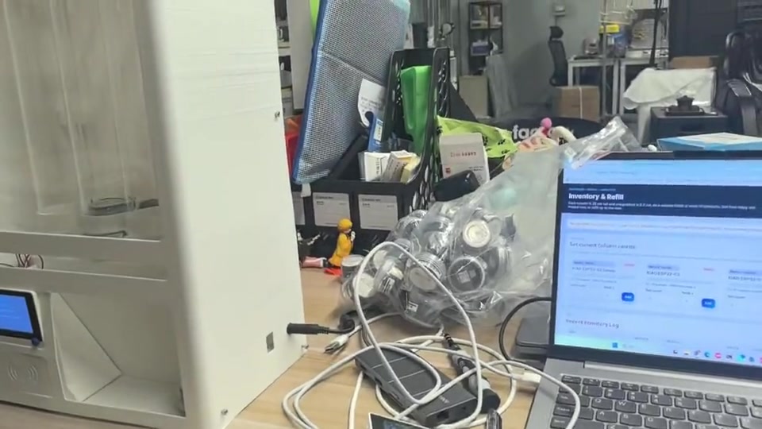
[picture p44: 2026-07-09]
xiao-vending-machine-v0/xiao-vending-machine-assemble-steps/assets/balance-dispense-testing-poster.jpg

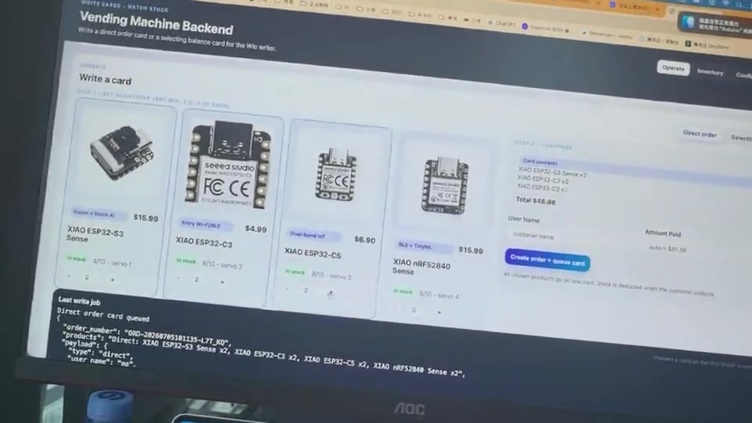
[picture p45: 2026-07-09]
xiao-vending-machine-v0/xiao-vending-machine-assemble-steps/assets/direct-dispense-testing-poster.jpg

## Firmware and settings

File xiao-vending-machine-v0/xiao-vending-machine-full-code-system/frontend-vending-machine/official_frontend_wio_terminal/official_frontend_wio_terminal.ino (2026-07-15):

#include <Wire.h>
#include <TFT_eSPI.h>
#include "Emakefun_RFID.h"
#include "SCServo.h"
#include <rpcWiFi.h>
#include <HTTPClient.h>

// =====================================================
// OFFICIAL FRONTEND VENDING MACHINE (Wio Terminal)
// =====================================================
// One of the two Wio Terminals in the system. This is the customer-facing
// reader that dispenses products. The other Wio (backend-full/wio-rfid-writer)
// writes the cards.
//
// Flow for every card:
//   1. Read the card and its selling type (written by the backend writer):
//        {"type":"direct",   "user_name":"..","order_number":"..","v":1}
//        {"type":"selecting","user_name":"..","v":1}
//   2. Ask backend-full for permission (no permission -> no dispense):
//        POST /api/frontend/verify-card
//   3. Dispense:
//        direct    -> dispense the reserved product (servo_id x quantity)
//        selecting -> customer picks products on screen within their balance;
//                     POST /api/frontend/selecting/checkout to spend + get plan
//   4. Report so the backend deducts / finalizes:
//        POST /api/frontend/dispense-complete
//
// The backend deducts stock at step 2/3 and refuses when a column needs a
// refill, so a valid card still will not dispense from an empty column.
//
// RFID: Emakefun MFRC522 over I2C 0x28 on Wire1 (Grove I2C), key FF*6,
//       payload across MIFARE blocks 4,5,6,8,9,10.
// Servos: Feetech SMS/STS bus servos ids 1..4 on Serial1 @ 1,000,000 baud.
//         Positions use the ZERO/MAX values calibrated with the testing_phase
//         1-a / 1-b sketches. One dispense = ZERO -> MAX -> ZERO.
// =====================================================

// ---------------- WIFI / BACKEND ----------------
const char* WIFI_SSID = "SEEED-MKT";
const char* WIFI_PASSWORD = "edgemaker2023";

// Same-WiFi backend example: "http://192.168.1.20:3000"
// Public deployment example:  "https://your-app.onrender.com"
const char* BACKEND_BASE_URL = "http://192.168.7.53:3000";

const char* DEVICE_ID = "frontend-1";
const char* API_KEY = "FRONTEND_1_SECRET";

bool wifiReady = false;

// ---------------- LCD ----------------
TFT_eSPI tft;

// ---------------- RFID ----------------
#define RFID_ADDR 0x28
MFRC522 mfrc522(RFID_ADDR);
MFRC522::MIFARE_Key rfidKey;
bool rfidReady = false;

// Must match the backend writer. Do not use sector trailer blocks 7 or 11.
const byte DATA_BLOCKS[] = {4, 5, 6, 8, 9, 10};
const int DATA_BLOCK_COUNT = sizeof(DATA_BLOCKS) / sizeof(DATA_BLOCKS[0]);
const int MAX_PAYLOAD_LEN = DATA_BLOCK_COUNT * 16;

// ---------------- SERVO ----------------
#define SERVO_NUM 4
SMS_STS st;
byte ID[SERVO_NUM] = {1, 2, 3, 4};

// ZERO (home) + MAX per servo id 1..4, captured with testing_phase 1-a and
// verified with 1-b. Re-run those sketches to recalibrate if the mechanism
// changes. MAX < ZERO here: the servos travel in the decreasing direction.
const s16 ZERO_POS[SERVO_NUM] = {2490, 2598, 2897, 3651};
const s16 MAX_POS[SERVO_NUM]  = {250, 262, 905, 1552};

const u16 MOVE_SPEED     = 2000;
const u8  MOVE_ACC       = 50;
const int SETTLE_TIMEOUT = 3000;   // ms max wait for one leg
const int ARRIVE_TOL     = 20;     // units; how close counts as arrived

bool present[SERVO_NUM] = {false, false, false, false};

// ---------------- STATE ----------------
enum State { WAIT_RFID, AUTH };
State state = WAIT_RFID;

// ---------------- SESSION ----------------
String currentCardUID = "";
String currentUserName = "";
String currentOrderNumber = "";

// selecting session (per-servo, index 0..3 == servo id 1..4)
float selBalance = 0;
long  selStock[SERVO_NUM]  = {0, 0, 0, 0};
float selPrice[SERVO_NUM]  = {0, 0, 0, 0};
long  selNeeds[SERVO_NUM]  = {0, 0, 0, 0};
long  selActive[SERVO_NUM] = {1, 1, 1, 1};
String selNames[SERVO_NUM];

// ---------------- DISPLAY (Seeed Studio branded UI) ----------------
// 320x240 redesign matching the static mockups in
// frontend-vending-machine/ui-for-each-phase. Only TFT_eSPI primitives are
// used so the whole look is portable. Palette in RGB565:
//   Seeed Green #8FC31F  +  deep "Seeed Blue" navy screens.
#define S565(r, g, b) ((uint16_t)((((r) & 0xF8) << 8) | (((g) & 0xFC) << 3) | ((b) >> 3)))
static const uint16_t C_BG      = S565(6, 40, 62);     // #06283E navy screen
static const uint16_t C_BG2     = S565(11, 46, 68);    // row / card surface
static const uint16_t C_BAR     = S565(1, 17, 28);     // status + hint bars
static const uint16_t C_GREEN   = S565(143, 195, 31);  // Seeed Green
static const uint16_t C_GREEN_D = S565(110, 154, 22);  // deep green
static const uint16_t C_INK     = S565(234, 244, 249); // near-white text
static const uint16_t C_MUTED   = S565(143, 174, 194); // secondary text
static const uint16_t C_AMBER   = S565(255, 176, 32);
static const uint16_t C_RED     = S565(255, 91, 98);
static const uint16_t C_INFO    = S565(67, 180, 228);
static const uint16_t C_LINE    = S565(30, 60, 82);
static const uint16_t C_GREENDIM = S565(20, 42, 10);

#define GLYPH_NONE  0
#define GLYPH_CHECK 1
#define GLYPH_CROSS 2
#define GLYPH_WARN  3
#define GLYPH_INFO  4
#define GLYPH_CARD  5
#define GLYPH_CLOCK 6
#define GLYPH_BOX   7
#define GLYPH_SPIN  8
#define GLYPH_LEAF  9
#define GLYPH_AUTO  255

void thickLine(int x0, int y0, int x1, int y1, uint16_t col, int t) {
  for (int i = -(t / 2); i <= t / 2; i++) {
    tft.drawLine(x0, y0 + i, x1, y1 + i, col);
    tft.drawLine(x0 + i, y0, x1 + i, y1, col);
  }
}

void drawGlyph(int cx, int cy, uint8_t g, uint16_t col) {
  switch (g) {
    case GLYPH_CHECK:
      thickLine(cx - 11, cy + 1, cx - 3, cy + 9, col, 3);
      thickLine(cx - 3, cy + 9, cx + 12, cy - 8, col, 3);
      break;
    case GLYPH_CROSS:
      thickLine(cx - 9, cy - 9, cx + 9, cy + 9, col, 3);
      thickLine(cx + 9, cy - 9, cx - 9, cy + 9, col, 3);
      break;
    case GLYPH_WARN:
      tft.drawTriangle(cx, cy - 13, cx - 14, cy + 11, cx + 14, cy + 11, col);
      tft.drawTriangle(cx, cy - 12, cx - 13, cy + 10, cx + 13, cy + 10, col);
      tft.fillRect(cx - 1, cy - 5, 3, 9, col);
      tft.fillRect(cx - 1, cy + 7, 3, 3, col);
      break;
    case GLYPH_INFO:
      tft.drawCircle(cx, cy, 13, col);
      tft.drawCircle(cx, cy, 12, col);
      tft.fillRect(cx - 1, cy - 7, 3, 3, col);
      tft.fillRect(cx - 1, cy - 2, 3, 10, col);
      break;
    case GLYPH_CARD:
      tft.drawRoundRect(cx - 14, cy - 10, 20, 20, 3, col);
      tft.drawRoundRect(cx - 13, cy - 9, 18, 18, 3, col);
      tft.fillRect(cx - 10, cy - 5, 7, 5, col);
      tft.drawFastVLine(cx + 10, cy - 6, 12, col);
      tft.drawFastVLine(cx + 13, cy - 8, 16, col);
      break;
    case GLYPH_CLOCK:
      tft.drawCircle(cx, cy, 13, col);
      tft.drawCircle(cx, cy, 12, col);
      thickLine(cx, cy, cx, cy - 7, col, 2);
      thickLine(cx, cy, cx + 5, cy + 3, col, 2);
      break;
    case GLYPH_BOX:
      tft.drawRect(cx - 12, cy - 6, 24, 16, col);
      tft.drawRect(cx - 12, cy - 7, 24, 17, col);
      tft.drawFastHLine(cx - 12, cy + 1, 24, col);
      tft.fillTriangle(cx - 12, cy - 6, cx, cy - 12, cx, cy - 6, col);
      tft.fillTriangle(cx + 12, cy - 6, cx, cy - 12, cx, cy - 6, col);
      break;
    case GLYPH_SPIN: {
      const int px[8] = {0, 10, 14, 10, 0, -10, -14, -10};
      const int py[8] = {-14, -10, 0, 10, 14, 10, 0, -10};
      for (int i = 0; i < 8; i++) {
        uint16_t c = (i == 0) ? col : (i == 7 ? C_GREEN_D : C_LINE);
        tft.fillCircle(cx + px[i], cy + py[i], 2, c);
      }
      break;
    }
    case GLYPH_LEAF:
      thickLine(cx, cy + 13, cx, cy - 3, col, 3);
      tft.fillTriangle(cx - 1, cy + 3, cx - 15, cy - 3, cx - 3, cy - 11, col);
      tft.fillTriangle(cx + 1, cy - 3, cx + 15, cy - 9, cx + 3, cy - 15, C_GREEN_D);
      break;
    default: break;
  }
}

void drawMedallion(int cx, int cy, uint8_t glyph, uint16_t col) {
  uint16_t dim = C_BG2;
  if (col == C_GREEN) dim = S565(20, 42, 10);
  else if (col == C_RED) dim = S565(50, 16, 18);
  else if (col == C_AMBER) dim = S565(50, 36, 6);
  else if (col == C_INFO) dim = S565(8, 36, 50);
  tft.fillCircle(cx, cy, 30, dim);
  tft.drawCircle(cx, cy, 30, col);
  tft.drawCircle(cx, cy, 29, col);
  if (glyph != GLYPH_NONE) drawGlyph(cx, cy, glyph, col);
}

// persistent seeed studio brand bar + live wifi indicator (top 26 px)
void drawStatusBar() {
  tft.fillRect(0, 0, 320, 26, C_BAR);
  tft.drawFastHLine(0, 26, 320, C_GREEN);
  tft.fillRoundRect(9, 7, 12, 12, 3, C_GREEN);
  tft.setTextSize(1);
  tft.setTextDatum(TL_DATUM);
  tft.setTextColor(C_GREEN, C_BAR);
  tft.drawString("seeed", 27, 9);
  tft.setTextColor(C_MUTED, C_BAR);
  tft.drawString("studio", 59, 9);
  bool wl = (WiFi.status() == WL_CONNECTED);
  uint16_t wc = wl ? C_GREEN : C_RED;
  tft.setTextDatum(TR_DATUM);
  tft.setTextColor(wc, C_BAR);
  tft.drawString(wl ? "online" : "offline", 298, 9);
  tft.fillCircle(309, 13, 3, wc);
}

void drawHintBar(const char* txt) {
  tft.fillRect(0, 214, 320, 26, C_BAR);
  tft.drawFastHLine(0, 214, 320, C_LINE);
  tft.setTextSize(1);
  tft.setTextDatum(ML_DATUM);
  tft.setTextColor(C_MUTED, C_BAR);
  tft.drawString(txt, 12, 228);
}

uint8_t fitSize(const char* s, int maxw, uint8_t maxSize) {
  int len = strlen(s);
  uint8_t sz = maxSize;
  while (sz > 1 && len * 6 * sz > maxw) sz--;
  return sz;
}

// Full-detail message screen: title=eyebrow (small, coloured), l1=headline,
// l2/l3=subtitle lines, colour selects the accent, glyph the status icon.
void displayScreenEx(const char* title, const char* l1, const char* l2,
                     const char* l3, uint16_t color, uint8_t glyph, const char* hint) {
  tft.fillScreen(C_BG);
  drawStatusBar();

  uint16_t accent = color;
  uint8_t g = glyph;
  if (color == TFT_GREEN)       { accent = C_GREEN; if (g == GLYPH_AUTO) g = GLYPH_CHECK; }
  else if (color == TFT_RED)    { accent = C_RED;   if (g == GLYPH_AUTO) g = GLYPH_CROSS; }
  else if (color == TFT_YELLOW) { accent = C_AMBER; if (g == GLYPH_AUTO) g = GLYPH_WARN; }
  else if (color == TFT_CYAN)   { accent = C_INFO;  if (g == GLYPH_AUTO) g = GLYPH_INFO; }
  else if (g == GLYPH_AUTO)     { g = GLYPH_NONE; }

  int y;
  if (g != GLYPH_NONE) { drawMedallion(160, 80, g, accent); y = 120; }
  else { y = 74; }

  tft.setTextDatum(TC_DATUM);
  if (title && title[0]) {
    tft.setTextSize(1);
    tft.setTextColor(accent, C_BG);
    tft.drawString(title, 160, y);
    y += 16;
  }
  if (l1 && l1[0]) {
    uint8_t ts = fitSize(l1, 300, 3);
    tft.setTextSize(ts);
    tft.setTextColor(C_INK, C_BG);
    tft.drawString(l1, 160, y);
    y += (ts >= 3 ? 30 : (ts == 2 ? 22 : 14));
  }
  tft.setTextSize(1);
  tft.setTextColor(C_MUTED, C_BG);
  if (l2 && l2[0]) { tft.drawString(l2, 160, y); y += 15; }
  if (l3 && l3[0]) { tft.drawString(l3, 160, y); y += 15; }

  drawHintBar(hint ? hint : "seeed studio   -   XIAO Vending");
}

// Backwards-compatible 5-arg entry used across the flows (auto glyph, no hint).
void displayScreen(const char* title, const char* l1, const char* l2, const char* l3, uint16_t color) {
  displayScreenEx(title, l1, l2, l3, color, GLYPH_AUTO, nullptr);
}

void showWelcome() {
  tft.fillScreen(C_BG);
  drawStatusBar();
  tft.setTextDatum(TC_DATUM);
  if (!rfidReady) {
    drawMedallion(160, 84, GLYPH_CARD, C_AMBER);
    tft.setTextSize(1); tft.setTextColor(C_AMBER, C_BG);
    tft.drawString("READER OFF", 160, 126);
    tft.setTextSize(3); tft.setTextColor(C_INK, C_BG);
    tft.drawString("Press A", 160, 144);
    tft.setTextSize(1); tft.setTextColor(C_MUTED, C_BG);
    tft.drawString("to start the RFID reader", 160, 182);
    drawHintBar("Press button A to begin");
  } else {
    drawMedallion(160, 80, GLYPH_CARD, C_GREEN);
    tft.setTextSize(1); tft.setTextColor(C_GREEN, C_BG);
    tft.drawString("WELCOME", 160, 120);
    tft.setTextSize(3); tft.setTextColor(C_INK, C_BG);
    tft.drawString("Scan your card", 160, 138);
    tft.setTextSize(1); tft.setTextColor(C_MUTED, C_BG);
    tft.drawString("Collect an order or shop your balance", 160, 176);
    drawHintBar("Tap a card on the reader");
  }
}

void showDispenseProgress(const char* who, byte id, int t, int times) {
  tft.fillScreen(C_BG);
  drawStatusBar();
  char buf[40];
  tft.setTextDatum(TL_DATUM);
  tft.setTextSize(1); tft.setTextColor(C_GREEN, C_BG);
  snprintf(buf, sizeof(buf), "DISPENSING  -  ITEM %d OF %d", t, times);
  tft.drawString(buf, 18, 44);
  tft.setTextSize(3); tft.setTextColor(C_INK, C_BG);
  snprintf(buf, sizeof(buf), "Column %d", id);
  tft.drawString(buf, 18, 66);
  tft.setTextSize(2); tft.setTextColor(C_MUTED, C_BG);
  snprintf(buf, sizeof(buf), "Servo %d", id);
  tft.drawString(buf, 18, 104);
  tft.setTextSize(1); tft.setTextColor(C_MUTED, C_BG);
  snprintf(buf, sizeof(buf), "Card: %s", who);
  tft.drawString(buf, 18, 134);
  tft.setTextDatum(TR_DATUM); tft.setTextSize(2); tft.setTextColor(C_GREEN, C_BG);
  snprintf(buf, sizeof(buf), "%d/%d", t, times);
  tft.drawString(buf, 302, 100);
  int bx = 18, by = 168, bw = 284, bh = 14;
  tft.drawRoundRect(bx, by, bw, bh, 4, C_LINE);
  float frac = times > 0 ? (float)t / times : 0;
  int fw = (int)((bw - 4) * frac);
  if (fw > 0) tft.fillRoundRect(bx + 2, by + 2, fw, bh - 4, 3, C_GREEN);
  drawHintBar("Please wait  -  keep the card in place");
}

void showBootSplash() {
  tft.fillScreen(C_BG);
  drawStatusBar();
  drawMedallion(160, 84, GLYPH_LEAF, C_GREEN);
  tft.setTextDatum(TC_DATUM);
  tft.setTextSize(3); tft.setTextColor(C_INK, C_BG);
  tft.drawString("XIAO Vending", 160, 128);
  tft.setTextSize(1); tft.setTextColor(C_MUTED, C_BG);
  tft.drawString("Powered by seeed studio", 160, 162);
  drawHintBar("Starting up  -  homing servos");
}

// ---------------- SERVO HELPERS ----------------
void moveTo(byte id, s16 target) {
  st.WritePosEx(id, target, MOVE_SPEED, MOVE_ACC);
  unsigned long start = millis();
  int startPos = st.ReadPos(id);
  int last = startPos;
  bool started = false;
  while (millis() - start < (unsigned long)SETTLE_TIMEOUT) {
    delay(50);
    int now = st.ReadPos(id);
    if (now < 0) continue;
    if (abs(now - (int)target) <= ARRIVE_TOL) return;
    if (!started && startPos >= 0 && abs(now - startPos) > 40) started = true;
    if (started && abs(now - last) < 4) return;
    last = now;
  }
}

// One actuation of servo index i: ZERO -> MAX -> ZERO (full mechanism cycle).
void dispenseOnce(int i) {
  if (!present[i]) return;
  moveTo(ID[i], MAX_POS[i]);
  moveTo(ID[i], ZERO_POS[i]);
}

void dispenseServo(int idx, int times, const char* who) {
  for (int t = 1; t <= times; t++) {
    Serial.print("[DISPENSE] "); Serial.print(who);
    Serial.print(" servo "); Serial.print(ID[idx]);
    Serial.print(" move "); Serial.print(t); Serial.print("/"); Serial.println(times);
    showDispenseProgress(who, ID[idx], t, times);
    dispenseOnce(idx);
    delay(300);
  }
}

void homeAllToZero() {
  for (int i = 0; i < SERVO_NUM; i++) {
    if (present[i]) st.WritePosEx(ID[i], ZERO_POS[i], MOVE_SPEED, MOVE_ACC);
  }
  unsigned long start = millis();
  while (millis() - start < (unsigned long)SETTLE_TIMEOUT) {
    bool allThere = true;
    for (int i = 0; i < SERVO_NUM; i++) {
      if (!present[i]) continue;
      int now = st.ReadPos(ID[i]);
      if (now < 0 || abs(now - (int)ZERO_POS[i]) > ARRIVE_TOL) { allThere = false; break; }
    }
    if (allThere) break;
    delay(40);
  }
}

// ---------------- JSON ----------------
String jsonValue(const String& json, const String& key) {
  String needle = "\"" + key + "\":";
  int p = json.indexOf(needle);
  if (p < 0) return "";
  p += needle.length();
  while (p < json.length() && (json[p] == ' ' || json[p] == '\t')) p++;
  if (p >= json.length()) return "";
  if (json[p] == '"') {
    int start = p + 1;
    int end = json.indexOf('"', start);
    if (end < 0) return "";
    return json.substring(start, end);
  }
  int end = json.indexOf(',', p);
  if (end < 0) end = json.indexOf('}', p);
  if (end < 0) end = json.length();
  String value = json.substring(p, end);
  value.trim();
  return value;
}

String jsonEscape(String value) {
  value.replace("\\", "\\\\");
  value.replace("\"", "\\\"");
  return value;
}

// Parse a fixed-length numeric JSON array: "key":[a,b,c,d]
void jsonNumberArray(const String& json, const String& key, float* out, int count) {
  for (int i = 0; i < count; i++) out[i] = 0;
  String needle = "\"" + key + "\":[";
  int p = json.indexOf(needle);
  if (p < 0) return;
  p += needle.length();
  int idx = 0;
  while (idx < count && p < json.length()) {
    while (p < json.length() && (json[p] == ' ' || json[p] == '\t')) p++;
    int end = p;
    while (end < json.length() && json[end] != ',' && json[end] != ']') end++;
    String num = json.substring(p, end);
    num.trim();
    out[idx++] = num.toFloat();
    if (end >= json.length() || json[end] == ']') break;
    p = end + 1;
  }
}

// Split "a|b|c|d" into up to count Strings.
void splitPipe(const String& value, String* out, int count) {
  for (int i = 0; i < count; i++) out[i] = "";
  int idx = 0, start = 0;
  while (idx < count) {
    int bar = value.indexOf('|', start);
    if (bar < 0) { out[idx++] = value.substring(start); break; }
    out[idx++] = value.substring(start, bar);
    start = bar + 1;
  }
}

// ---------------- RFID ----------------
void stopRFID() {
  mfrc522.PICC_HaltA();
  mfrc522.PCD_StopCrypto1();
}

String getScannedUIDString() {
  String uidText = "";
  for (byte i = 0; i < mfrc522.uid.size; i++) {
    if (mfrc522.uid.uidByte[i] < 0x10) uidText += "0";
    uidText += String(mfrc522.uid.uidByte[i], HEX);
    if (i < mfrc522.uid.size - 1) uidText += " ";
  }
  uidText.toUpperCase();
  return uidText;
}

bool authenticateBlock(byte blockAddr) {
  MFRC522::StatusCode status = (MFRC522::StatusCode)mfrc522.PCD_Authenticate(
    MFRC522::PICC_CMD_MF_AUTH_KEY_A, blockAddr, &rfidKey, &(mfrc522.uid));
  if (status != MFRC522::STATUS_OK) {
    Serial.print("[RFID] Auth failed block "); Serial.print(blockAddr);
    Serial.print(": "); Serial.println(mfrc522.GetStatusCodeName(status));
    return false;
  }
  return true;
}

bool readPayloadFromCard(String &payload) {
  payload = "";
  for (int b = 0; b < DATA_BLOCK_COUNT; b++) {
    byte blockAddr = DATA_BLOCKS[b];
    if (!authenticateBlock(blockAddr)) return false;
    byte buffer[18];
    byte size = sizeof(buffer);
    MFRC522::StatusCode status = (MFRC522::StatusCode)mfrc522.MIFARE_Read(blockAddr, buffer, &size);
    if (status != MFRC522::STATUS_OK) {
      Serial.print("[RFID] Read failed block "); Serial.print(blockAddr);
      Serial.print(": "); Serial.println(mfrc522.GetStatusCodeName(status));
      return false;
    }
    for (int i = 0; i < 16; i++) {
      if (buffer[i] == 0) continue;
      payload += (char)buffer[i];
    }
  }
  payload.trim();
  Serial.print("[RFID] Payload: "); Serial.println(payload);
  return payload.length() > 0;
}

void initRFID() {
  // Visible feedback so pressing A always does something on screen.
  displayScreen("RFID", "Checking reader...", "", "", TFT_CYAN);
  delay(150);
  Wire1.begin();
  // PCD_Reset() is now bounded (see Emakefun_RFID.cpp), so PCD_Init can no longer
  // hang when the reader is missing - the version register tells us if it is there.
  mfrc522.PCD_Init();
  byte v = mfrc522.PCD_ReadRegister(mfrc522.VersionReg);
  Serial.print("[RFID] Version register: 0x");
  if (v < 0x10) Serial.print("0");
  Serial.println(v, HEX);
  if (v == 0x00 || v == 0xFF) {
    Serial.println("[RFID] Reader not responding (check Grove I2C port / 0x28)");
    rfidReady = false;
    displayScreen("RFID NOT FOUND", "Use the Grove I2C port", "(same as testing), 0x28", "then press A to retry", TFT_RED);
  } else {
    Serial.println("[RFID] Reader ready");
    mfrc522.PCD_AntennaOn();
    rfidReady = true;
    state = AUTH;
    showWelcome();
  }
}

// ---------------- WIFI / HTTP ----------------
const char* wifiStatusText(int s) {
  switch (s) {
    case WL_CONNECTED:       return "connected";
    case WL_NO_SSID_AVAIL:   return "SSID not found (2.4/5G?)";
    case WL_CONNECT_FAILED:  return "auth failed (password?)";
    case WL_CONNECTION_LOST: return "connection lost";
    case WL_DISCONNECTED:    return "disconnected";
    case WL_IDLE_STATUS:     return "idle";
    case WL_NO_SHIELD:       return "no wifi core!";
    default:                 return "working...";
  }
}
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
void loop() {
  if (!rfidReady) {
    if (digitalRead(WIO_KEY_A) == LOW) { initRFID(); delay(400); }
    return;
  }
  scanRFIDCard();
  delay(40);
}

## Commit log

2026-07-07 Add docs and code
    [card_ledger.csv, card_meta.csv, cards.csv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]
2026-07-07 update steps of assembling
    [L holder.stl, LED diffuser.stl, LED holder .stl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]
2026-07-08 update code
    [product_meta.csv]
2026-07-15 Add compressed real-operation demos and product-specific dispenser.
    Document the common vs product-specific dispenser STLs, shrink the operation videos for GitHub, and refresh related assembly assets and READMEs.
    [card_ledger.csv, card_meta.csv, cards.csv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]
2026-10-07 Publish the Fab vending site with V0 display models.
    GitHub Pages can serve the program page from docs, and the exploded view loads GLB derivatives of the released CAD instead of parsing every source file on first paint.
2026-10-07 Show exploded parts at one shared CAD scale.
    Independent display sizes made a foot look almost as large as the enclosure, so viewers could not judge the real machine.
2026-10-08 Publish the English and Chinese site from the Pages folder.
    GitHub Pages already serves /docs on this branch, so the language chooser, en, and ch live there and websites points at the same folder.
    [machines.json]
2026-10-09 Freeze Version 0 as the reference and publish the site from docs.
    Move the machine under xiao-vending-machine-v0, add community and release records, and open each contribution button as a prefilled GitHub issue in a new tab.
    [L holder.stl, LED diffuser.stl, LED holder .stl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]
2026-10-19 Publish the latest local site with the colored assembly and lab directory.
